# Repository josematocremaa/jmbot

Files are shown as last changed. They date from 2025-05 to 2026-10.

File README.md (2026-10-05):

# jmbot

**A five-axis robot arm with a gripper, teleoperated in Cartesian space with a 3D mouse. Built with ROS 2, Gazebo and Mbed.**

<p align="center">
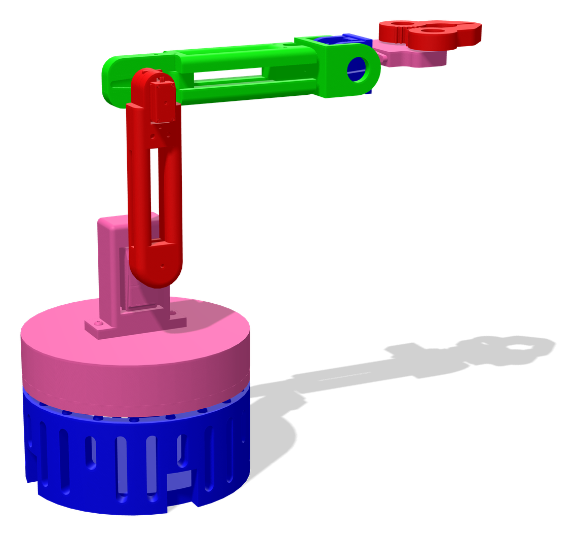
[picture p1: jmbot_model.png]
Render of the jmbot arm model at its zero pose
  
</p>

<!-- TODO: add the thesis title, the supervisor, a link to the thesis PDF,
     and a photo or video of the real arm. -->

jmbot is the robot arm I designed and built for my bachelor's thesis at Universidad Carlos III de Madrid (UC3M) in 2025. This repository holds its ROS 2 package and its firmware. The same software drives a Gazebo simulation of the arm and the real hardware:

- A URDF model built from the CAD meshes, simulated in Gazebo with `ros2_control`.
- Cartesian teleoperation. A 3Dconnexion SpaceMouse sets the velocity of the tool, and a differential inverse-kinematics controller turns it into joint positions.
- A serial bridge and Mbed firmware that move the real motors: a stepper for the base and five servos for the other joints and the gripper.

## How it works

```mermaid
flowchart TD
    SM["3Dconnexion SpaceMouse<br/>spacenav driver"] -->|"/spacenav/joy"| SC["spacenav_controller.py<br/>axes to Cartesian velocity"]
    SC -->|"twist, buttons"| CC["cartesian_controller.py<br/>differential IK with PyKDL"]
    CC -->|"/position_controller/commands"| PC["position_controller<br/>ros2_control in Gazebo"]
    CC -->|"/position_controller/commands"| JC["joint_controller.py<br/>serial bridge"]
    JC -->|"USB serial, 19200 baud"| FW["mbed.cpp<br/>firmware"]
    FW --> ST["Base stepper"]
    FW --> SV["Five servos"]
```

1. The `spacenav` driver publishes the six axes and two buttons of the mouse on `/spacenav/joy`.
2. `spacenav_controller.py` scales the axes into a Cartesian velocity command and publishes it as a `Twist` at 100 Hz. Pushing the mouse all the way asks for about 100 mm/s. The two buttons open and close the gripper.
3. `cartesian_controller.py` holds the kinematic chain of the arm in PyKDL. For every command it solves the differential inverse kinematics with the pseudo-inverse of the Jacobian, integrates the joint velocities over a 10 ms step and publishes the new joint positions. A step that would take a joint past its limit is discarded.
4. The joint positions go out on `/position_controller/commands`. Two consumers can listen to that topic at the same time:
   - In simulation, a `ros2_control` position controller running inside Gazebo.
   - On the real arm, `joint_controller.py`, which converts the positions to degrees and sends them over USB serial to the microcontroller.
5. The firmware in `mbed.cpp` parses each frame, steps the base motor and sets the servo angles.

## The arm

| Joint | Motion | Actuator | Firmware pins | Joint in the URDF |
| --- | --- | --- | --- | --- |
| 1 | Base rotation | Stepper motor, 0.9° per step, through a 58:19 gear reduction | STEP `D4`, DIR `D7` | `Base_base` |
| 2 | Shoulder | Servo | `D9` | `Base_hombro` |
| 3 | Elbow | Servo | `D5` | `Hombro_medio` |
| 4 | Wrist pitch | Servo | `D3` | `UNION_MUNECA` |
| 5 | Wrist roll | Servo | `D6` | `muneca_pinza` |
| Gripper | Open and close | Servo | `D10` | `pinza_final` |

### Kinematic model

`cartesian_controller.py` builds the chain from these Denavit-Hartenberg parameters (lengths in mm):

| Joint | a | α | d | θ offset |
| --- | --- | --- | --- | --- |
| 1 | 0 | −90° | 140 | 0° |
| 2 | 106 | 0° | 0 | −90° |
| 3 | 140 | 0° | 0 | +90° |
| 4 | 0 | +90° | −28 | +90° |
| 5 | 0 | 0° | 70 | 0° |

With every joint at zero, the tool sits at (210, −28, 246) mm from the base origin.

### Serial protocol

Each command is one ASCII frame: `<`, six signed three-digit angles in whole degrees, and `>`.

```
<+090-045+030+000+012+100>
```

The values are, in order, base, shoulder, elbow, wrist pitch, wrist roll and gripper. `joint_controller.py` sends the frames at 19200 baud on `/dev/ttyACM0`.

## Repository layout

| Path | Contents |
| --- | --- |
| `urdf/model.urdf` | Robot description: links, joints, inertias and the `ros2_control` position interfaces |
| `urdf/meshes/` | Meshes exported from the CAD model |
| `launch/jmbot.launch.py` | Starts Gazebo with an empty world, spawns the arm and loads the controllers |
| `config/controller.yaml` | `ros2_control` configuration: a joint state broadcaster and a position controller for the six joints |
| `scripts/spacenav_controller.py` | SpaceMouse input to Cartesian velocity and gripper commands |
| `scripts/cartesian_controller.py` | Differential inverse kinematics and joint-limit check |
| `scripts/joint_controller.py` | Bridge from joint commands to the serial protocol |
| `scripts/prueba.py` | Stand-alone forward and inverse kinematics check of the chain |
| `mbed.cpp` | Mbed OS firmware for the stepper and the servos |

## Running it

Requirements:

- ROS 2 with Gazebo: `ros_gz_sim`, `ros_gz_bridge`, `gz_ros2_control`, `ros2_control`, `ros2_controllers`, `robot_state_publisher` and `xacro`.
- The `spacenav` ROS package and the `spacenavd` daemon, for the 3D mouse.
- PyKDL (`python_orocos_kdl_vendor`), NumPy and `pyserial`.
- For the real arm, a board running Mbed OS 6 and the Mbed `Servo` library.

Build the package in a ROS 2 workspace:

```bash
mkdir -p ~/ros2_ws/src && cd ~/ros2_ws/src
git clone https://github.com/josematocremaa/jmbot.git
cd ~/ros2_ws
rosdep install --from-paths src --ignore-src -r -y
colcon build --packages-select jmbot
source install/setup.bash
```

Start the simulation:

```bash
ros2 launch jmbot jmbot.launch.py
```

To move the simulated arm without a 3D mouse, publish joint positions in radians:

```bash
ros2 topic pub --once /position_controller/commands std_msgs/msg/Float64MultiArray \
  "{data: [0.5, 0.3, -0.3, 0.0, 0.0, 0.0]}"
```

To teleoperate it, run each of these in its own terminal:

```bash
ros2 run spacenav spacenav_node
ros2 run jmbot spacenav_controller.py
ros2 run jmbot cartesian_controller.py
```

To drive the real arm with the same commands, flash the firmware, connect the board over USB and start the serial bridge from the workspace root:

```bash
python3 src/jmbot/scripts/joint_controller.py
```

### Firmware

`mbed.cpp` is the `main.cpp` of an Mbed OS 6 project. Add the Mbed `Servo` library to the project, build it for your board and flash it. The pin assignment is in the table above.

## Credits

- The package skeleton and the launch file started from the [`gz_ros2_control_demos`](https://github.com/ros-controls/gz_ros2_control) examples, which are licensed under Apache-2.0.
- The kinematics use [Orocos KDL](https://github.com/orocos/orocos_kinematics_dynamics) through its Python bindings.

## License

MIT. See [LICENSE](LICENSE). The launch file keeps its original Apache-2.0 header.

## Author

José Manuel Merlo Sánchez ([LinkedIn](https://www.linkedin.com/in/jose-manuel-merlo-sanchez-545507241)). This was my final thesis for the Bachelor's Degree in Industrial Electronics and Automation Engineering at Universidad Carlos III de Madrid, 2025.

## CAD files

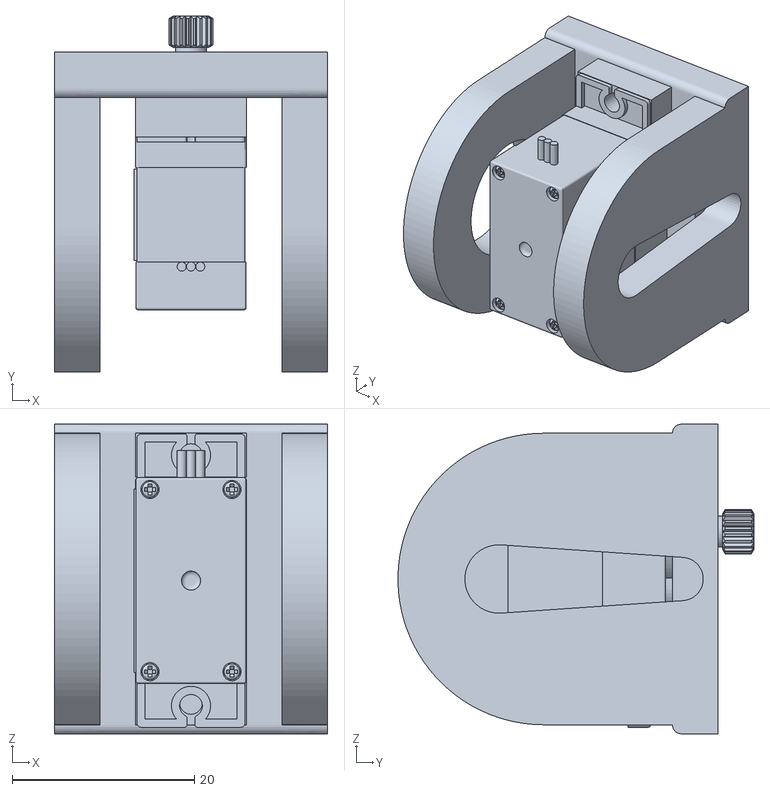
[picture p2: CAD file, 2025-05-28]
urdf/meshes/UNION_bueno.stl
30.0 x 39.1 x 34.0

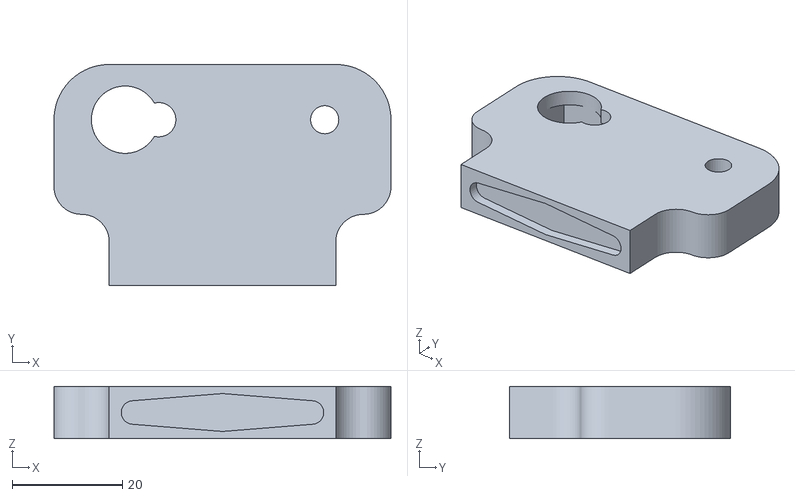
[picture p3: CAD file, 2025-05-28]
urdf/meshes/Pinza_base_ws.stl
61.0 x 40.0 x 9.50

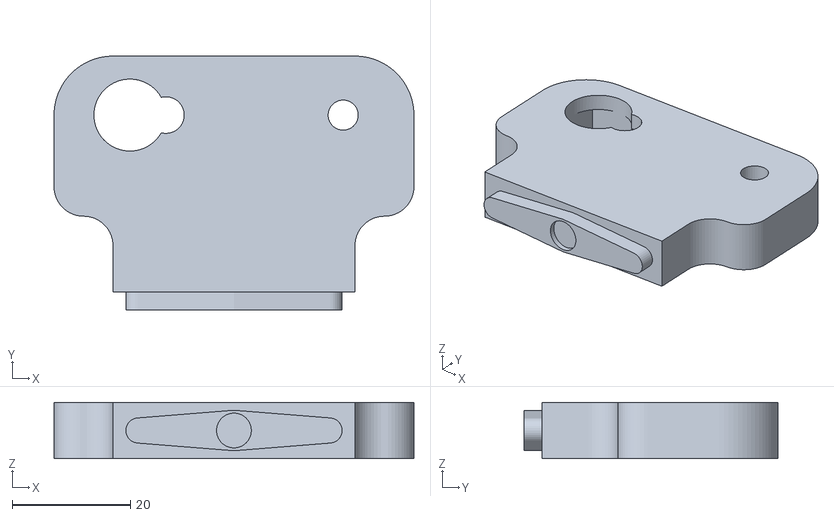
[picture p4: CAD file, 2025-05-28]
urdf/meshes/Pinza_base_bueno.stl
61.0 x 43.0 x 9.50

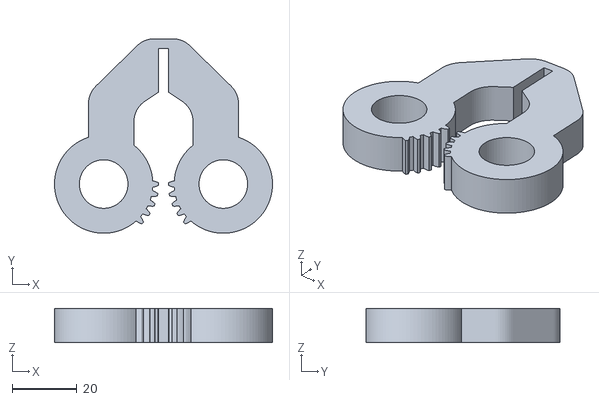
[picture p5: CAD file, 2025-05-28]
urdf/meshes/Pinza_bueno.stl
67.3 x 60.0 x 10.5

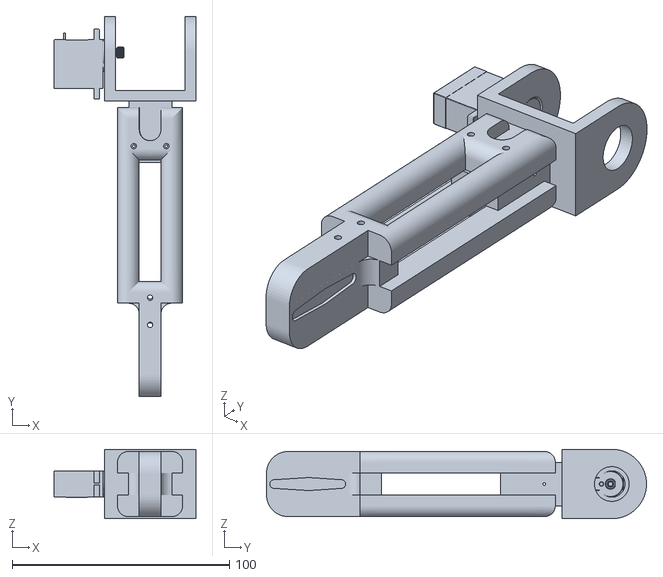
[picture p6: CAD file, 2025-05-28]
urdf/meshes/brazomedio_bueno.stl
65.3 x 175.0 x 32.0

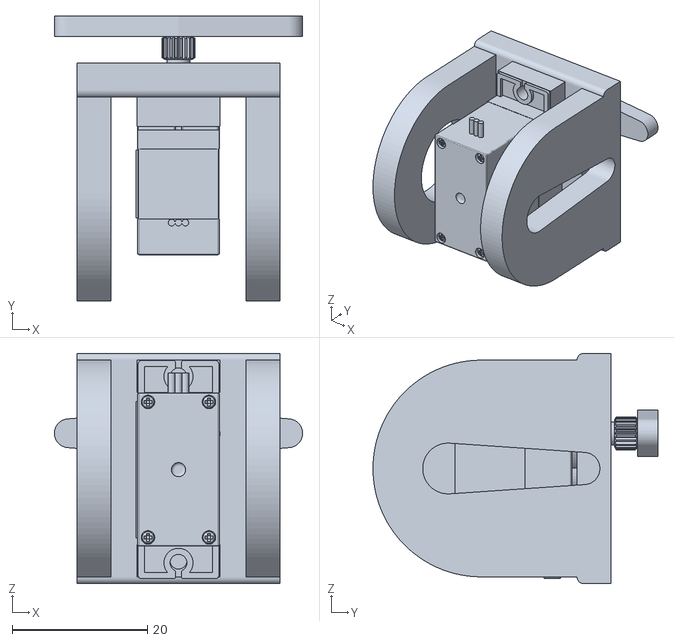
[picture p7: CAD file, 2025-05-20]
urdf/meshes/UNION.stl
36.6 x 42.1 x 34.0

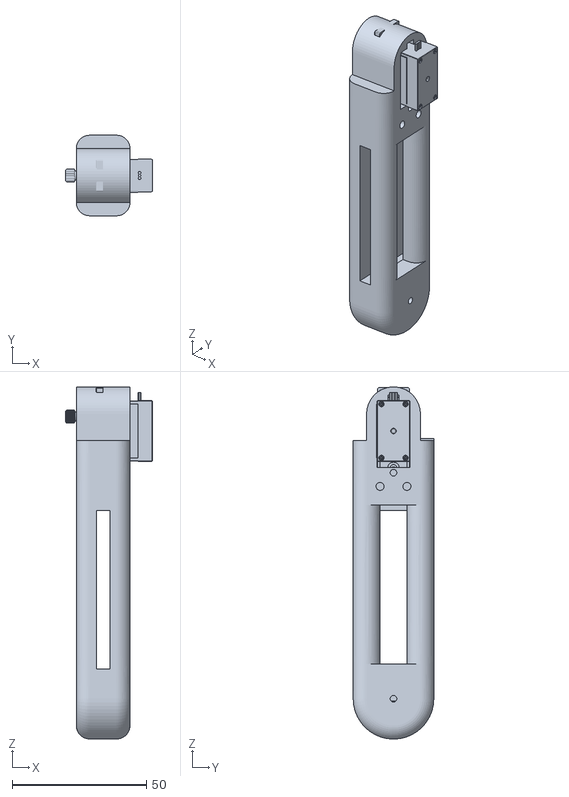
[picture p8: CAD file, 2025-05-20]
urdf/meshes/Hombro_pos_bueno.stl
32.2 x 30.0 x 131.0

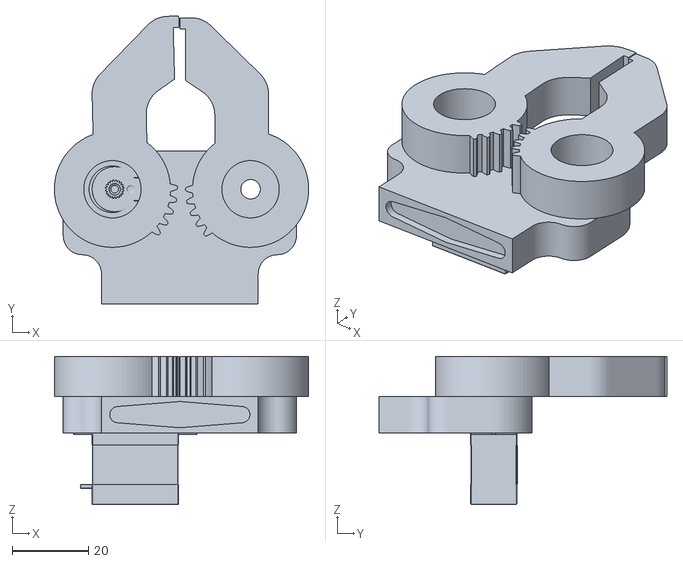
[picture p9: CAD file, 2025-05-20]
urdf/meshes/Pinza.stl
66.5 x 75.3 x 38.8

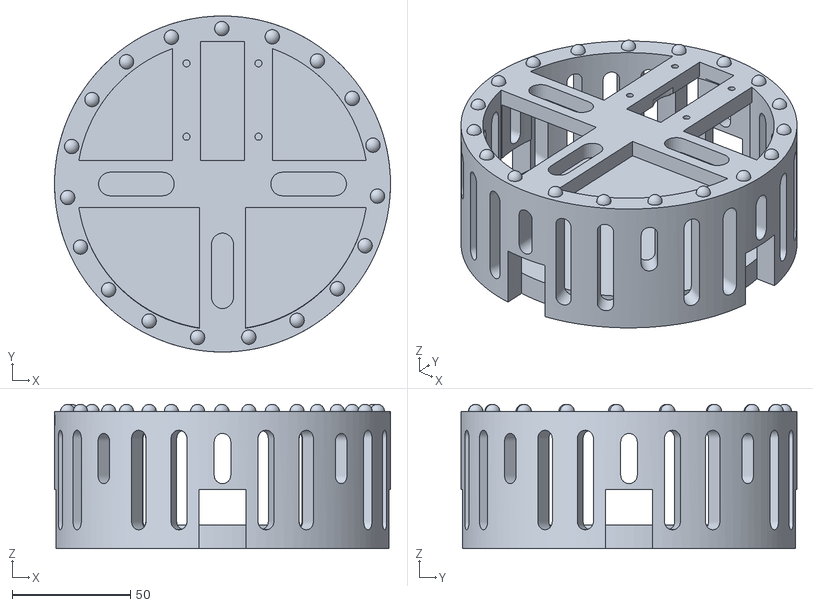
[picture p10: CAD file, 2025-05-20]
urdf/meshes/Base_base.stl
142.0 x 142.0 x 61.0

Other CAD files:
urdf/meshes/brazomedio.stl
urdf/meshes/Hombro_pos_prueba.stl
urdf/meshes/Pinza_base_prueba.stl
urdf/meshes/Hombro_pos_com3.stl
urdf/meshes/Pinza_sola.stl
urdf/meshes/Hombro_pos_com4.stl
urdf/meshes/Hombro_pos.stl
urdf/meshes/Hombro_pos_com.stl
urdf/meshes/Pinza_cambio.stl
urdf/meshes/Base_base.obj
urdf/meshes/Base_base_1.obj
urdf/meshes/Base_base_1.stl
urdf/meshes/Hombro_pos.obj
urdf/meshes/Hombro_pos_bueno.obj
urdf/meshes/Hombro_pos_com.obj
urdf/meshes/Hombro_pos_com2.obj
urdf/meshes/Hombro_pos_com2.stl
urdf/meshes/Hombro_pos_com3.obj
urdf/meshes/Hombro_pos_com4.obj
urdf/meshes/Hombro_pos_prueba.obj
urdf/meshes/Pinza.obj
urdf/meshes/Pinza_base_bueno.obj
urdf/meshes/Pinza_base_cambio.obj
urdf/meshes/Pinza_base_cambio.stl
urdf/meshes/Pinza_base_prueba.obj
urdf/meshes/Pinza_base_ws.obj
urdf/meshes/Pinza_bueno.obj
urdf/meshes/Pinza_cambio.obj
urdf/meshes/Pinza_sola.obj
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

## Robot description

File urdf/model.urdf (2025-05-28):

<robot name="jmbot" xmlns:xacro="http://ros.org/wiki/xacro">

<!-- Link ficticio anclado al mundo -->
<!-- Joint fijo que ancla 'base' al suelo -->
  <link name="world"/>
  <joint name="world_joint" type="fixed">
      <parent link="world"/>
      <child link="base"/>
      <origin rpy="0.0 0.0 0.0" xyz="0.0 0.0 0.0"/>
  </joint>

  <link name="base">
  <gazebo reference="base">
  </gazebo>
    <visual>
      <geometry>    
        <mesh filename="package://jmbot/urdf/meshes/Base_base.obj"/>
      </geometry>
      <material name="blue">
        <color rgba="0.0 0.0 1.0 1"/>
      </material>
    </visual>
    <collision>
      <geometry>
        <mesh filename="package://jmbot/urdf/meshes/Base_base.stl"/>
      </geometry>
    </collision>
    <inertial>
      <mass value="1"/>
     <inertia ixx="0.0043125" ixy="0" ixz="0" iyy="0.0043125" iyz="0" izz="0.0075"/>
    </inertial>
  </link>

  <joint name="Base_base" type="revolute">
    <parent link="base"/>
    <child link="Ensamblaje_base"/>
    <origin xyz="0 0 0" rpy="0 0 0"/>
    <axis xyz="0 0 1"/>
    <limit lower="-3.14" upper="3.14" effort="1000000000" velocity="100"/>
    <dynamics damping="0.1"/>
  </joint>

  <!-- Ensamblaje_base -->
  <link name="Ensamblaje_base">
    <visual>
      <geometry>
        <mesh filename="package://jmbot/urdf/meshes/Ensamblaje_base_fix.obj"/>
      </geometry>
      <material name="pink">
        <color rgba="1.0 0.4 0.7 1"/>
      </material>
    </visual>
    <collision>
      <geometry>
        <mesh filename="package://jmbot/urdf/meshes/Ensamblaje_base_fix.stl"/>
      </geometry>
    </collision>
    <inertial>
      <mass value="0.7"/>
      <inertia ixx="0.0117" ixy="0" ixz="0" iyy="0.0177" iyz="0" izz="0.01"/>
    </inertial>
  </link>

  <joint name="Base_hombro" type="revolute">
    <parent link="Ensamblaje_base"/>
    <child link="hombro"/>
    <origin xyz="0 0 14" rpy="0 0 0"/>
    <axis xyz="1 0 0"/>
    <limit lower="-3.14" upper="3.14" effort="10000000000" velocity="100"/>
    <dynamics damping="0.01" friction="0.0"/>
  </joint>

  <!-- Hombro -->
  <link name="hombro">
    <visual>
      <geometry>
        <mesh filename="package://jmbot/urdf/meshes/Hombro_pos_prueba.obj"/>
      </geometry>
      <material name="red">
        <color rgba="1.0 0.0 0.0 1"/>
      </material>
    </visual>
    <collision>
      <geometry>
        <mesh filename="package://jmbot/urdf/meshes/Hombro_pos_prueba.stl"/>
      </geometry>
    </collision>
    <inertial>
      <mass value="0.2"/>
      <inertia ixx="0.0034" ixy="0" ixz="0" iyy="0.0032" iyz="0" izz="0.0004"/>
    </inertial>
  </link>

  <joint name="Hombro_medio" type="revolute">
    <parent link="hombro"/>
    <child link="brazomedio"/>
    <origin xyz="0 0 11" rpy="0 0 0"/>
    <axis xyz="1 0 0"/>
    <limit lower="-3.14" upper="3.14" effort="10000000000" velocity="100"/>
    <dynamics damping="0.1"/>
  </joint>

  <!-- Brazomedio -->
  <link name="brazomedio">
    <visual>
      <geometry>
        <mesh filename="package://jmbot/urdf/meshes/brazomedio_bueno.obj"/>
      </geometry>
      <material name="green">
        <color rgba="0.0 1.0 0.0 1"/>
      </material>
    </visual>
    <collision>
      <geometry>
        <mesh filename="package://jmbot/urdf/meshes/brazomedio_bueno.stl"/>
      </geometry>
    </collision>
    <inertial>
      <mass value="0.1"/>
      <inertia ixx="0.0076" ixy="0" ixz="0" iyy="0.0076" iyz="0" izz="0.00027"/>
    </inertial>
  </link>

  <joint name="UNION_MUNECA" type="revolute">
    <parent link="brazomedio"/>
    <child link="UNION"/>
    <origin xyz="0 13.5 0" rpy="0 0 0"/>
    <axis xyz="1 0 0"/>
    <limit lower="-3.14" upper="3.14" effort="1000000000" velocity="100"/>
    <dynamics damping="0.1"/>
  </joint>

  <!-- UNION -->
  <link name="UNION">
    <visual>
      <geometry>
        <mesh filename="package://jmbot/urdf/meshes/UNION_bueno.obj"/>
      </geometry>
      <material name="blue2">
        <color rgba="0.0 0.0 1.0 1"/>
      </material>
    </visual>
    <collision>
      <geometry>
        <mesh filename="package://jmbot/urdf/meshes/UNION_bueno.stl"/>
      </geometry>
    </collision>
    <inertial>
      <mass value="0.05"/>
      <inertia ixx="0.00045" ixy="0" ixz="0" iyy="0.00047" iyz="0" izz="0.00019"/>
    </inertial>
  </link>

  <joint name="muneca_pinza" type="revolute">
    <parent link="UNION"/>
    <child link="pinza"/>
    <origin xyz="0 0 0" rpy="0 0 0"/>
    <axis xyz="0 1 0"/>
    <limit lower="-3.14" upper="3.14" effort="10000000000" velocity="100"/>
    <dynamics damping="0.1"/>
  </joint>

  <!-- Pinza -->
  <link name="pinza">
    <visual>
      <geometry>
        <mesh filename="package://jmbot/urdf/meshes/Pinza_base_bueno.obj"/>
      </geometry>
      <material name="pink2">
        <color rgba="1.0 0.4 0.7 1"/>
      </material>
    </visual>
    <collision>
      <geometry>
        <mesh filename="package://jmbot/urdf/meshes/Pinza_base_bueno.stl"/>
      </geometry>
    </collision>
    <inertial>
      <mass value="0.01"/>
      <inertia ixx="0.00049" ixy="0" ixz="0" iyy="0.00047" iyz="0" izz="0.00019"/>
    </inertial>
  </link>


 <joint name="pinza_final" type="revolute">
    <parent link="pinza"/>
    <child link="pinza_extremo"/>
    <origin xyz="0 0 0" rpy="0 0 0"/>
    <axis xyz="0 0 1"/>
    <limit lower="-3.14" upper="3.14" effort="10000000000" velocity="100"/>
    <dynamics damping="0.1"/>
  </joint>

  <!-- Pinza -->
  <link name="pinza_extremo">
    <visual>
      <geometry>
        <mesh filename="package://jmbot/urdf/meshes/Pinza_bueno.obj"/>
      </geometry>
      <material name="red">
        <color rgba="1.0 0.0 0.0 1"/>
      </material>
    </visual>
    <collision>
      <geometry>
        <mesh filename="package://jmbot/urdf/meshes/Pinza_bueno.stl"/>
      </geometry>
    </collision>
    <inertial>
      <mass value="0.01"/>
      <inertia ixx="0.00049" ixy="0" ixz="0" iyy="0.00047" iyz="0" izz="0.00019"/>
    </inertial>
  </link>
  <!-- Añadir plugin de ROS Control -->

 <ros2_control name="GazeboSimSystem" type="system">
  <hardware>
    <plugin>gz_ros2_control/GazeboSimSystem</plugin>
  </hardware>
  <joint name="Base_base">
    <command_interface name="position"/>
    <state_interface name="position"/>
  </joint>
  <joint name="Base_hombro">
    <command_interface name="position"/>
    <state_interface name="position"/>
  </joint>
  <joint name="Hombro_medio">
    <command_interface name="position"/>
    <state_interface name="position"/>
  </joint>
  <joint name="UNION_MUNECA">
    <command_interface name="position"/>
    <state_interface name="position"/>
  </joint>
  <joint name="muneca_pinza">
    <command_interface name="position"/>
    <state_interface name="position"/>
  </joint>
  <joint name="pinza_final">
    <command_interface name="position"/>
    <state_interface name="position"/>
  </joint>
</ros2_control>

<gazebo>
  <plugin filename="libgz_ros2_control-system.so" name="gz_ros2_control::GazeboSimROS2ControlPlugin">
    <parameters>$(find jmbot)/config/controller.yaml</parameters>
    <controller_manager_prefix_node_name>controller_manager</controller_manager_prefix_node_name>
  </plugin>
</gazebo>
<gazebo reference="world_link">
  <static>true</static>
</gazebo>
</robot>

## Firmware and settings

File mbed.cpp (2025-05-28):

#include "mbed.h"
#include <cstdlib>
#include "Servo.h"




Servo hombro(D9);
Servo codo(D5);
Servo muneca(D3);
Servo muneca2(D6);
Servo pinza(D10);

DigitalOut dirPin(D7);
DigitalOut stepPin(D4);

const float resolution = 0.9;
int angle=0;
int turning_time=1000000;

BufferedSerial pc(USBTX, USBRX, 19200);
int ang1=0;
int ang2=0;
int ang3=0;
int ang4=0;
int ang5=0;
int hola=0;


void move(int angle, int turning_time) {
 dirPin=1;
 angle=angle * 3.0526;  //58 /19
 int steps = angle  / resolution;
 
 int ms = (turning_time * resolution) / (2 * angle);

 for (int i = 0; i < steps; i++) {
    stepPin=1;
    wait_us(ms); // Demora de 2 segundos
    stepPin=0;
    wait_us(ms); // Demora de 2 segundos
}
wait_us(500000); // Demora de 2 segundos
 }


struct serial_msg
{
    uint8_t data[26]; // make room for 4*5 bytes  + 2 bytes (frame counter)
    int size;
};

//funciones

void readMessage(const char * buffer, serial_msg & msg)
{
    msg.size = 0;
    char c = '0';
    int index = 0;
    int start = -1;
    int end = -1;
    bool hitOnce = false;
    printf("buffer: %s\n", buffer);
    while (true)
    {
        c = buffer[index++];

        if (c == '<')
        {
            
            start = index;
            continue;
        }
        else if (c == '>' && start != -1)
        {
            end = index;
            break;
        }
        else 
         {
             memcpy(msg.data + msg.size, &c, 1);
             printf("Caracter copiado: %c | Tamano actual: %d\r\n", c, msg.size);
             //printf("msg %s", msg.data);
             msg.size++;
         }
        if (index==26)
        {
            if (hitOnce)
            {
                break;
            }
            else
            {
               index=0;
               hitOnce = true;
            }
        }
    }
    printf("start: %d end: %d\n", start,end);
}


//<-234+678912345678934>


// Create a bufferedSerial object with a 9600 baud rate.


int main(void)
{
    serial_msg msg_in;
    char c;
    char buffer[26]={0};
    int index = 0;
    int size=0;
    char num1_str[5]= {0};
    char num2_str[5]= {0};
    char num3_str[5]= {0};
    char num4_str[5]= {0};
    char num5_str[5]= {0};
    char num6_str[5]= {0};
   // pc.write("Iniciando comunicacion...\r\n", 26);  // Enviar un mensaje al PC
    codo.calibrate(0.0009, 180.0);
    muneca.calibrate(0.0009, 180.0);
    muneca2.calibrate(0.0009, 180.0);
    pinza.calibrate(0.0009, 180.0);
    hombro.calibrate(0.001, 135.0);
    

while (true)
{
    memset(buffer, 0, sizeof(buffer));  // Limpiar buffer antes de leer
    memset(msg_in.data, 0, sizeof(msg_in.data));  // Limpiar mensaje anterior

                
            
                //ThisThread::sleep_for(1s);
            //move(-90, turning_time);  // Regresar
                //ThisThread::sleep_for(1s);
    while ((size = pc.read(buffer, 26)) > 0)
    {   // Si hay datos disponibles
        
        readMessage(buffer, msg_in);
        // pc.write("Buffer recibido: ", 17);
        // pc.write(buffer, size);
        // pc.write("\r\n", 2);
            

             if (msg_in.size>=24) //no cuento <> 
                {  // Fin de mensaje
                       
                    // pc.write("Recibido: ", 10);
                    // pc.write(msg_in.data, msg_in.size);

                    // Extraer los primeros 4 caracteres y convertirlos a un número
                    memcpy(num1_str, msg_in.data, 4);
                    angle = atoi(num1_str);
                    move(angle, turning_time);
                    printf( "Num1: %d, \r\n", angle);

                    // Extraer los siguientes 4 caracteres y convertirlos a un número
                    memcpy(num2_str, msg_in.data + 4, 4);
                    ang1 = atoi(num2_str);
                    hombro.position(ang1);
                    //printf( "Num2: %d, \r\n", ang1);

                   // Extraer los siguientes 4 caracteres y convertirlos a un número
                    memcpy(num3_str, msg_in.data + 8, 4);
                    ang2 = atoi(num3_str);
                    codo.position(ang2);
                   // printf( "Num3: %d, \r\n", ang2);

                   // Extraer los siguientes 4 caracteres y convertirlos a un número
                    memcpy(num4_str, msg_in.data + 12, 4);
                    ang3 = atoi(num4_str);
                    muneca.position(ang3);
                   // printf( "Num4: %d, \r\n", ang3);

                   // Extraer los siguientes 4 caracteres y convertirlos a un número
                    memcpy(num5_str, msg_in.data + 16, 4);
                    ang4 = atoi(num5_str);
                    muneca2.position(ang5);
                    //printf( "Num5: %d, \r\n", ang4);
                    // Extraer los siguientes 4 caracteres y convertirlos a un número
                    memcpy(num6_str, msg_in.data + 20, 4);
                    ang5 = atoi(num6_str);
                    pinza.position(ang5);
                    //printf( "Num5: %d, \r\n", ang5);
                }
         rtos::ThisThread::sleep_for(1s);
    }              
   // <-234+678+123-567+567>
   //<-490-435-436+543-465>
}

}

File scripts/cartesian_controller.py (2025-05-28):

#!/usr/bin/env python3

import numpy as np
import PyKDL as kdl
import rclpy
from rclpy.node import Node
from std_msgs.msg import Float64MultiArray
from geometry_msgs.msg import Twist
from std_msgs.msg import Int8

GRIPPER_INCR = 0.01 # rad

class CartesianController(Node):
    def __init__(self):
        super().__init__('cartesian_controller')
        self.publisher_ = self.create_publisher(Float64MultiArray, '/position_controller/commands', 10)
        self.subscription_buttons = self.create_subscription(
            Int8,
            'buttons',
            self.buttons_callback,
            10
        )
        self.subscription_buttons
        self.subscription_twist = self.create_subscription(
            Twist,
            'twist',
            self.listener_callback,
            10)
        self.subscription_twist

        self.q = kdl.JntArray(5)
        
        self.q[0] = 0
        self.q[1] = 0
        self.q[2] = 0
        self.q[3] = 0
        self.q[4] = 0
        
        self.q_min = kdl.JntArray(5)
        self.q_max = kdl.JntArray(5)

        self.q_max[0] = 3.14
        self.q_min[0] = -3.14
        self.q_max[1] = 2
        self.q_min[1] = -2
        self.q_max[2] = 3.14
        self.q_min[2] = -3
        self.q_max[3] = 1.57
        self.q_min[3] = -1.5
        self.q_max[4] = 1.57
        self.q_min[4] = -1.57

        self.q_gripper = 0
        self.q_gripper_min = -3.14
        self.q_gripper_max = 3.14

        self.buttons = 0

        a, b, c, d, e  = 140, 106, 140, 70, 28

        self.chain = kdl.Chain()
        #                  A alpha D theta
        H_0_1 = kdl.Frame.DH(0,np.deg2rad(-90),a,0)
        H_1_2 = kdl.Frame.DH(b,0,0,np.deg2rad(-90))
        H_2_3 = kdl.Frame.DH(c,0,0,np.deg2rad(+90))
        H_3_4 = kdl.Frame.DH(0,np.deg2rad(+90),-e,np.deg2rad(+90))
        H_4_5 = kdl.Frame.DH(0,0,d,0)

        axis = kdl.Joint(kdl.Joint.RotZ)

        self.chain.addSegment(kdl.Segment(axis, H_0_1))
        self.chain.addSegment(kdl.Segment(axis, H_1_2))
        self.chain.addSegment(kdl.Segment(axis, H_2_3))
        self.chain.addSegment(kdl.Segment(axis, H_3_4))
        self.chain.addSegment(kdl.Segment(axis, H_4_5))

        self.fk_solver = kdl.ChainFkSolverPos_recursive(self.chain)
        self.ik_solver_vel = kdl.ChainIkSolverVel_pinv(self.chain)
        self.ik_solver = kdl.ChainIkSolverPos_NR(self.chain, self.fk_solver, self.ik_solver_vel,100, 1e-6)

    def buttons_callback(self, msg):
        self.buttons = msg.data

    def listener_callback(self, msg):
        # self.get_logger().info(f'Recibido objetivo: {msg}')
        #print("q actual:", [self.q[i] for i in range(self.q.rows())])

        tw = kdl.Twist()
        tw.vel = kdl.Vector(msg.linear.x, msg.linear.y, msg.linear.z)
        tw.rot = kdl.Vector(msg.angular.x, msg.angular.y, msg.angular.z)
        #print("Twist recibido:", tw)
        
        q_dot = kdl.JntArray(5)
        ret = self.ik_solver_vel.CartToJnt(self.q, tw, q_dot)

        if ret != 0:
            print(ret)
        # print([q_dot[i] for i in range(q_dot.rows())])

        dt = 0.01
        q_nueva = kdl.JntArray(5)
        en_rango = True

        #corregir limites articulares

        for i in range(5):
            q_temp = self.q[i] + q_dot[i] * dt

            if not (self.q_min[i] <= q_temp <= self.q_max[i]):
                en_rango = False
            else:
                q_nueva[i] = q_temp

            #self.q[i] += q_dot[i]

        if en_rango:
            self.q = q_nueva
            out = Float64MultiArray()
            out.data = [self.q[i] for i in range(self.q.rows())]

            if self.buttons == 1:
                temp = self.q_gripper + GRIPPER_INCR
            elif self.buttons == -1:
                temp = self.q_gripper - GRIPPER_INCR
            else:
                temp = self.q_gripper

            if self.q_gripper_min <= temp <= self.q_gripper_max:
                self.q_gripper = temp

            out.data.append(self.q_gripper)

            self.publisher_.publish(out)
            self.get_logger().info(f'out: {out}')
        else:
            self.get_logger().warn('Movimiento anulado: se exceden los límites articulares.') 

        # # Posición inicial
        # q_init = kdl.JntArray(5)
        # for i in range(5):
        #     q_init[i] = 0
        # # q_a = (0, 24.83, 37.83, 0, 27.34, 0)
        # # for i in range(5):
        # #     q[i] = np.deg2rad(q_a[i])


        # Solvers
        

        
        # # Usar objetivo recibido
        # x, y, z = self.objetivo
        # p_in = kdl.Frame(kdl.Vector(x, y, z))
        # q_result = kdl.JntArray(5)
        # ret = ik_solver.CartToJnt(q_init, p_in, q_result)

        # if ret >= 0:
        #     q_out_list = [q_result[i] for i in range(q_result.rows())]
        #     q_out_deg = np.degrees(q_out_list)

        #     # Publicar en el tópico
        #     msg = Float64MultiArray()
        #     msg.data = q_out_deg.tolist()
        #     self.publisher_.publish(msg)

        #     self.get_logger().info(f'Publicado en topic: {msg.data}')
        # else:
        #     self.get_logger().warn('Falló la resolución IK')

def main(args=None):
    rclpy.init(args=args)
    node = CartesianController()
    rclpy.spin(node)
    node.destroy_node()
    rclpy.shutdown()

if __name__ == '__main__':
    main()
